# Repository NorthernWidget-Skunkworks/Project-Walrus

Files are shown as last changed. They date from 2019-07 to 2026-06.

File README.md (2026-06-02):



# The Walrus: A Pressure and Temperature Sensor for Water-Level and Barometric Measurements

Walrus pup; photo by Max Smith

***Our Walrus sensor, like this Walrus pup, is equally at home on land or in the water.*** *[Photo by Max Smith](https://commons.wikimedia.org/wiki/File:Walrus_-_Kamogawa_Seaworld_-_pup_-1.jpg)*

## Overview

The **Walrus** is an open-source sensor that measures temperature and pressure. It may be used in the air as a barometer or underwater as part of a system -- combined with barometric compensation -- to obtain changes in water level.

Walrus HardMount v0.2.0
***Hard-mount variant of the Walrus.*** Major components are labeled. The pads to attach the watertight plug for the cable (i.e. the "HardMount"), on left, are currently unpopulated. These may be used for this kind of connector, or may have wires soldered directly to them before being embedded in an epoxy or other potting (i.e., waterproofing and encapsulating) compound.

### Technical specifications

#### Size

Dimensions: 42.0 x 12.7 cm

>> ADD MASS once I get access to a lab balance again <<

#### Operating ranges

**Power**
* Input Voltage: 3.3 to 5.5 V DC
* Logic Voltage: 0 to Vcc (Will operate at same logic level as input power supply)

**Sensors**
* Temperature: -40 to +85 C
* Pressure, typical: 0 to 2 atm (i.e. barometer to 10 m water depth)
* Pressure, maximum, untested: 0 to 30 atm (i.e. barometer to 290 m water depth)
* Cable length: 3 m (I2C) or 1000 m (RS-485).

The pressure transducer contains an internal temperature sensor, and a secondary (and more accurate) external temperature sensor is also mounted on the *Walrus*. This external sensor is the [MCP9808](http://www.microchip.com/mymicrochip/filehandler.aspx?ddocname=en556196) in an 8-MSOP package. This sensor has a range of -40 to 125 C.

RS-485 communications allow for a signal to be transmitted over long distances, but require a device that can decode this signal, such as our [Project-Longbow](https://github.com/NorthernWidget-Skunkworks/Project-Longbow).

#### MS5803 pressure sensor variants

The pressure operating range and resolution depend on the MS5803 variant installed. All variants use the same footprint and firmware (with appropriate coefficient selection).

| Variant | Application | Range | Resolution @ OSR=4096 | Water depth equiv. |
|---|---|---|---|---|
| [MS5803-01BA](https://www.te.com/commerce/DocumentDelivery/DDEController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) | Barometer | 10–1300 mbar | ~0.012 mbar | ~0.12 mm |
| [MS5803-02BA](https://www.te.com/commerce/DocumentDelivery/DDEController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) | Shallow water | 0–2 bar | ~0.020 mbar | ~0.2 mm |
| [MS5803-05BA](https://www.te.com/commerce/DocumentDelivery/DDEController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) | Medium depth | 0–6 bar | ~0.050 mbar | ~0.5 mm |
| [MS5803-14BA](https://www.te.com/commerce/DocumentDelivery/DDEController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) | Deep water | 0–14 bar | ~0.200 mbar | ~2 mm |

The **MS5803-02BA** is the standard variant (pressure measurements to ~10 m water depth). The **MS5803-01BA** converts the Walrus into a high-resolution barometer. 1 mbar ≈ 1 cm of freshwater at standard conditions.

Pressure values are stored in the I2C register map as µBar (int32). All variants fit within int32 range (~2.1 billion µBar max).

#### Resolution

Pressure: see MS5803 variant table above
Temperature sensor within pressure transducer (typical): +/- 2.0 C
External temperature sensor (typical): +/- 0.5 C

## Circuit board and assembly

The Walrus comes in two forms:
* [Large form factor, through-hole mount](https://github.com/NorthernWidget-Skunkworks/Project-TPDH-Walrus/tree/master/Hardware_LargePTH): This is the legacy board with support for I2C and full-duplex RS-485 communication
* [Smaller form factor, solder pads for wires or a waterproof plug](https://github.com/NorthernWidget-Skunkworks/Project-TPDH-Walrus/tree/master/Hardware_HardMount): This current version makes better use of board space and utilizes a half-duplex RS-485 bus in addition to an I2C bus.

### Files

The files for production are located in folders starting with the word "Hardware". These folders contain:

* "\*.brd" and "\*.sch" files. These are the circuit board and its schematic for use with the EAGLE CAD software, which you can download for free: https://www.autodesk.com/products/eagle/free-download
* A "\*.csv" file that contains the "BoM" -- the bill of materials. This lists all required parts to construct the board
* A ZIP archive containing a set of "Gerber" files. These are the files that machines use to create a circuit board and a stencil to help you to apply solder paste (see below)

### Circuit board specifications

* 2-layer copper
* Minimum trace width: 0.2 mm
* Single-sided
* Surface mount components

All Walrus boards are **single-sided** and use only **surface-mount components** for rapid fabrication using standard equipment.

### Producing circuit boards

We strongly recommend that circuit boards be printed by a reputible manufacturer. Many such industries exist in China, India, and developing or developed countries.

### Populating circuit boards

Before you can start to populate the circuit board, meaning adding components to it, you will need solder paste and a stencil. If you have access to a laser cutter, you can create your own stencil (https://learn.adafruit.com/smt-manufacturing/laser-cut-stencils). If you do not, the company that prints the circuit boards should be able to provide one. If all else fails, you can try to cut out a stencil with a small knife, or use a solder-paste syringe, though both of these methods can lead to difficulties (such as bridged connections). Additional information on how to stencil can be found here: https://www.sparkfun.com/tutorials/58.

To help you in using the stencil, we provide STL files for 3D-printable plates in each of the hardware directories. These plates hold the board in place and provide a level surface on which to use the stencil.

>> ADD PLATE FOR HARDMOUNT <<

After this, you can use a tweezers and steady hands, or a pick-and-place machine, to gently place each component over the right pads, and in the right orientation. Do not worry if they are slightly misaligned; the surface tension of the solderi, once it is melted, will help to rotate the components into place.

### Reflowing circuit boards

"Reflowing" is the process of heating solder until it flows and attaches to components. A basic introduction is here: https://learn.sparkfun.com/tutorials/electronics-assembly/reflow

There are four major ways to reflow:
1. Using a professional oven (see link above)
2. With a customized toaster oven: See https://www.sparkfun.com/tutorials/60, and a basic internet search will show you many, many other ideas
3. You can also use a simple electrical skillet -- the kind that you might use to make some food. https://www.sparkfun.com/tutorials/59
4. Using a hot-air rework station; this is a bit time-intensive, but lets you control the heat, and I often use it for small boards. https://learn.sparkfun.com/tutorials/how-to-use-a-hot-air-rework-station/all

After reflowing, you may need to clean up jumped connections using **solder wick**.

### Debugging circuit boards

After reflow is complete, check if everything worked. Do you have any jumped connections? Any remaining solder paste that hasn't been reflowed? This can be the trickiest part, and one for which access to a multimeter is essential. An oscilloscope and a digital logical analyzer can help too. Debugging electronic circuit boards is a process that requires significant skill and practice, so be sure that you can work with someone with some expertise. I would suggest an electrical engineering student or professor at a local university.

## Wiring and pinout

"Pin" is the name of the pin as labeled on the board. "Wire" is the color of the [Alpha Wire 5004C cable](https://www.digikey.com/product-detail/en/alpha-wire/5004C-SL001/5004CSL001-ND/484976) that we use; you may use something different based on what manufacturers exist where you are; that's okay, just record the color convention! (We sometimes use another cable in which we use a white wire for SDA and a green wire for SCL, but have found that Alpha Wire brand works best.)

>> Add image of cable ends (optional) and find how to integrate with housing section; cabling is a distinct topic, but the step of attaching the cable lies within the housing-construction step <<

### HardMount with plug

Here we assume that you are using standard Alpha Wire cables with waterproof attachments, available in [3-meter](https://www.digikey.com/en/products/detail/alpha-wire/AR0400101-SL357/6555492) and [1-meter](https://www.digikey.com/en/products/detail/alpha-wire/AR0400101-SL356/6555491) lengths; the 3-meter length is our standard because this is the longest that it can be and still communicate reliably via I2C. Because of the wire insulation colors available for these cables and the locations of their attachment points to the [4-pin "HardMount" plug](https://www.digikey.com/product-detail/en/te-connectivity-amp-connectors/1838893-2/A97650-ND/1764165) ([3D model](https://www.traceparts.com/en/product/allied-electronics-automation-m12-panel-mnt-male-4-way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)), **our HardMount devices do NOT match standard wire-color definitions (or any kind of standard)**. Wire-color definitions are:

| **Color** | **Connection** |
|---|---|
| Brown | V+ (3.3-5.5 V) |
| White | GND |
| Black | SIG1: SDA or RS-485 A |
| Blue | SIG2: SCL or RS-485 B |

### Large-form-factor/PTH design: standard wiring suggestion

*These are our more standard wire-color suggestions*

| **Color** | **Connection** |
|---|---|
| Red | V+ (3.3-5.5 V) |
| Black | GND |
| Brown | SIG1: SDA or RS-485 A (RX+, TX+) |
| Orange | SIG2: SCL or RS-485 B (RX-, TX-) |

If you attach your own wire, pins on the Walrus are as follows, looking at the top side with the screw hole away from you:
* Top left: SIG1: SDA for I2C; A (+) for RS-485
* Top right: SIG 2: SCL for I2C; B (-) for RS-485
* Bottom left: VCC (3.3V to 5.5V)
* Bottom right: GND

HardMount attachment points

## Upload the firmware

### Downloading and installing the Arduino IDE

Go to https://www.arduino.cc/en/main/software. Choose the proper IDE version for your computer. For Windows, we suggest the non-app version to have more control over Arduino; this might change in the future. You will have to add custom libraries, so the web version will not work (at least, as of the time of writing). Download and install the Arduino IDE. Open it to begin the next steps.

### AVR ISP

To install firmware on the Walrus, you use the [2x3-pin ICSP (also called ISP) header](https://www.digikey.com/product-detail/en/3m/929665-09-03-I/3M156313-06-ND/681796) with a special device called an "in-circuit system programmer" (or just "in-system programmer; yup, that's what the acronym stands for).

Many devices exist to upload firmware, including:
* The official [AVR ISP mkII](http://ww1.microchip.com/downloads/en/DeviceDoc/Atmel-42093-AVR-ISP-mkII_UserGuide.pdf) (no longer produced but available used)
* Using an [Arduino as an ISP](https://www.arduino.cc/en/tutorial/arduinoISP)
* The versatile [Olimex AVR-ISP-MK2](https://www.olimex.com/Products/AVR/Programmers/AVR-ISP-MK2/open-source-hardware)
* The [Adafruit USBtinyISP](https://www.adafruit.com/product/46)

***Note: Be sure to download and/or update drivers for your ISP.***

### Uploading the firmware

Using an AVR ISP, upload the proper firmware programs from the ["Firmware" directory](Firmware) in this repository using the Arduino software:
* Large form factor PTH board
  * I2C mode: No firmware required, but fuses must be set (see instructions, below)
  * RS-485 mode: [Longbow_2BA_0x6B](Firmware/Longbow_2BA_0x6B) (This firmware is for the 02BA; you will need to switch these with other coefficients, available in the commented and uncommented lines of /Firmware/Walrus_I2C_5BA, to modify this for a different transducer pressure range.)
* Small form factor hard-mount board
  * I2C mode: Set the fuses (see instructions below) and then upload [Walrus_I2C_5BA](/Firmware/Walrus_I2C_5BA/) (This firmware is for the 05BA; there are lines in this code to comment and uncomment to modify it for other versions of the Walrus.)
  * RS-485 mode: [Longbow_2BA_0x6B_HalfDuplex](Firmware/Longbow_2BA_0x6B_HalfDuplex) (This firmware is for the 02BA; you will need to switch these with other coefficients, available in the commented and uncommented lines of /Firmware/Walrus_I2C_5BA, to modify this for a different transducer pressure range.)

>> @bschulz1701: could you provide a link to the repo (is it TPDH lib) for "  * I2C mode: No firmware required. Library communicates directly with sensors via their built-in I2C addresses."

**Instructions:**

1. Open the Arduino IDE.
2. Follow [these instructions](https://github.com/SpenceKonde/ATTinyCore/blob/master/Installation.md) to install the [ATTinyCore board definitions](https://github.com/SpenceKonde/ATTinyCore)
3. Select [ATTiny1634](https://github.com/SpenceKonde/ATTinyCore/blob/master/avr/extras/ATtiny_1634.md) **(No bootloader)**
4. Plug your ISP of choice into your computer (via a USB cable) and onto the 6-pin header. There are two ways to place it on; the header is aligned such that the ribbon cable should be facing away from the board while programming. If this fails without being able to upload, try flipping the header around. This should both power the board and provide communications.
5. Go to Tools --> Programmer and select the appropriate programmer based on what you are using.
6. Go to Tools --> Burn Bootloader. Yes, we know that you just selected "ATTiny1634 (No bootloader)", but this step sets the fuses, which configure their internal oscillator and brown-out detection.
7. Unless you are configuring a large-form-factor Walrus in I2C mode (in which case you are now done), open the appropriate firmware (linked above). Then go to Sketch --> Upload Using Programmer. After several seconds, you learn whether you succeeded or failed. Hopefully it worked!

Upload using programmer

***Uploading using the in-system programmer.***

***Important note for Linux users:*** You must supply permissions to the Arduino IDE for it to be able to use the ICSP, or you will have to run it using `sudo`. The former option is better; the latter is easier in the moment.

## Register map and firmware internals

The Walrus firmware runs on an ATtiny1634 microcontroller and exposes an I2C register map to the host logger. The default I2C address is `0x4D`.

Two layouts exist: the **current firmware** (deployed) and the **proposed** layout under [NW-Device-Specification](https://github.com/NorthernWidget/NW-Device-Specification) Schema 1, which the firmware will be updated to implement.

### Current register map (deployed firmware)

26-byte array. Identity fields (MODEL, GROUPID, INDID, FIRMWAREID) mixed into sensor data. Status ready flag is bit 7.

```
0x00        CTRL/Status   bit 7=ready; bits 1:0=update rate selector (0–3)
0x01        —             unused
0x02–0x05   Pressure      int32, µBar (library: val/1000.0 → mBar)
0x06–0x09   Temp ext      int32, 1/10000 °C (MCP9808 external sensor)
0x0A–0x0D   Temp MS5803   int32, 1/10000 °C (MS5803 internal sensor)
0x0E–0x0F   MODEL         uint16 (0x5702)
0x10–0x11   —             gap (nothing loaded)
0x12–0x13   GROUPID       uint16
0x14–0x15   INDID         uint16
0x16–0x17   FIRMWAREID    uint16 (0x0001)
```

### Proposed register map (NW-Device-Specification Schema 1)

Two 32-byte pages. Identity moves entirely to Page 0 (EEPROM). Sensor data in Page 1 (SRAM). No calibration page (MS5803 coefficients are read from its internal PROM at startup).

**Page 0 (0x00–0x1F) — Identity (EEPROM)**

```
Block 0 (0x00–0x07)   Core identity
  0x00        0x01              Schema (NW-Device-Specification v1)
  0x01–0x06   'W','a','l','r','u','s'   Device name (ASCII)
  0x07        0x00              Null padding

Block 1 (0x08–0x0F)   Version
  0x08        HW major
  0x09        HW minor
  0x0A        FW patch          (NW combined-repo convention)
  0x0B–0x0D   0x00,0x00,0x00    Unused (combined repo)
  0x0E–0x0F   0x00,0x00         Reserved

Block 2 (0x10–0x17)   Serial number
  0x10–0x11   0x5702            Board type ('W'=0x57, revision index 2; matches MODEL)
  0x12–0x13   [manufacture]     Group ID
  0x14–0x15   [manufacture]     Unique ID
  0x16–0x17   0x00,0x00         FirmwareID (legacy, reserved)

Block 3 (0x18–0x1F)   Integrity + administration
  0x18–0x1C   0x00 ×5           Reserved
  0x1D        0x00              Magic byte (reserved; purpose TBD)
  0x1E        [computed]        CRC-8 of bytes 0x00–0x1D
  0x1F        0x4D              I2C address (writable; 0xFF = use default)
```

**Page 1 (0x20–0x3F) — Sensor data (SRAM)**

```
Block 0 (0x20–0x27)   MS5803 — pressure + temperature
  0x20        Status       bit 0=ready, bit 1=MS5803 fault, bit 2=ext temp fault,
                           bit 7=pan-fault
  0x21        Extended faults (reserved, 0x00)
  0x22–0x25   Pressure     int32, µBar, little-endian
  0x26–0x27   Temp MS5803  int16, 0.01 °C, little-endian

Block 1 (0x28–0x2F)   External temperature sensor (MCP9808)
  0x28–0x29   Temp ext     int16, 0.01 °C, little-endian
  0x2A–0x2F   Reserved

Block 2–3 (0x30–0x3F)   Reserved
```

## Housing

### Large-form-factor PTH design

Walrus PTH v0.0.0 with enclosure

***Walrus v0.0.0 PTH and its housing.*** *Left: 3D-printed top of the housing; the slits are to prevent large material from hitting the sensor. Center: the bottom of the housing. Self-tapping holes are to screw the board onto this housing. The cable entering the housing through a tightly-fitting hole on the "south" side of the image has not yet been stripped to expose the ends of the individual wires. A different variant of the housing is longer to allow the user to strip more of the cable if desired while maintaining the cable jacketing in contact with the hole. Top right: Walrus v0.0.0. This fully-functional initial version is significantly larger than the current unit. Note the pressure transducer (white circle) at top left, and the fact that this has pins and hardware for a full-duplex RS-485 connection. Bottom right: U.S. penny for scale; 19.05 mm (0.75 inch) diameter.*

### HardMount design

Render of Walrus enclosure
***Render of the enclosure design.*** *The epoxy encapsulation tray sits within a wider cylinder containing a screen designed to keep sediment out. Design still in progress (19 June 2020).*

### How to build

#### Materials and components required

##### All models

* 3D printer filament: ABS suggested
* Two-part epoxy: [3M DP270 Clear](https://multimedia.3m.com/mws/media/66773O/3mtm-scotch-weldtm-epoxy-potting-compound-adhesive-dp270.pdf); can be purchased from [McMaster-Carr](https://www.mcmaster.com/7467A274)
* Conformal coating to help protect components during epoxy encapsulation. We suggest [MG 419D](https://www.mgchemicals.com/products/conformal-coatings/acrylic-conformal-coating-419d) ([Digi-Key purchase link](https://www.digikey.com/product-detail/en/mg-chemicals/419D-55ML/473-1388-ND)). If you prefer a silicone conformal coat, we suggest [MG 422C](https://www.mgchemicals.com/products/conformal-coatings/422c-silicone-conformal-coating), though we recommend this instead for an external (rather than internal, as this will be), flexible coat.

##### HardMount with Plug

* [4-pin "HardMount" plug](https://www.digikey.com/product-detail/en/te-connectivity-amp-connectors/1838893-2/A97650-ND/1764165) ([3D model](https://www.traceparts.com/en/product/allied-electronics-automation-m12-panel-mnt-male-4-way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))
* HardMount cable: **Alpha Wire AR0400105-SL357** (-40 PVC jacket)
  * [Alpha Wire page](http://www.Alpha Wire.com/en/Products/Connectivity/AlphaConnect/Cordsets/AR0400105)
  * [Example from DigiKey](https://www.digikey.com/product-detail/en/alpha-wire/AR0400105-SL357/AR0400105SL357-ND/6555497)
  * Comes in a [variety of lengths from 0.6 to 20 meters](http://www.Alpha Wire.com/en/Products/Connectivity/AlphaConnect/Cordsets/AR0400105) ([Digi-Key search results](https://www.digikey.com/products/en/cable-assemblies/circular-cable-assemblies/448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))
  * User may choose a cable that terminates in a plug, alongside a matching recepticle in the wall of the data-logger box, for a specialized solution that does not require cable glands.
* One [#2-56 x 3/16" thread-cutting screw](https://www.fastenal.com/products/details/0143391) per board to fasten it to the housing for the epoxy encapsulation

##### PTH or "HardMount" design without plug

* 7x [\#4-24 self-tapping screws](https://www.polycase.com/screws-mbr-100) ([Additional link: untested but probably identical screw from Fastenal](https://www.fastenal.com/products/details/32244))
  * 3x to hold board in place
  * 4x to to attach the lid of the 3D-printed enclosure

*Assuming that we are using a 4-wire connection instead of the full-bridge RS-485 (supported by the large-form-factor/PTH board) because this is being phased out in favor of a 4-wire half-bridge.*

* [4-conductor Alpha Wire](https://www.digikey.com/product-detail/en/alpha-wire/5004C-SL001/5004CSL001-ND/484976), soldered to pads or rings

#### 3D printing the housing

Subfolders of the "3Dprint" directory contain "STL" files that you can use with a program called "[Slic3r](https://slic3r.org/)" to create 3-D printable parts for your housing. Assuming that you have a Prusa 3D printer, you will want to download the [Prusa variant of Slic3r](https://www.prusa3d.com/prusaslicer/). This comes with the appropriate setup files and information to help you configure the printer and print your parts.

>> Link to all housings once designed <<

>> TO DO: Options for HardMount with (and perhaps without) the plug. <<

#### Cabling

##### HardMount with Plug

Solder the HardMount plug onto the four SMD pads with the notch (for plug orientation) at the bottom side of the board. The best way to do this is to:
* Add small pillows of solder to each of the four pads, enough to create contact with the HardMount solder cups but not so much that it is not possible to slide the HardMount plug over them.
* Slide the HardMount plug on; it will take a bit of finesse to keep it from being pushed off of the solder pillows.
* Using some Blu Tack (or equivalent), fix the board and HardMount plug in place
* Double-check that the notch in the HardMount plug is on the back side of the board
* Solder on the first connection
* Check whether the board is straight; reflow the solder as needed until the connection is secure
* Solder the second connection
* Flip the board, ensuring that it is straight (if not, make changes)
* Solder the other two solder-cup connections

##### PTH or "HardMount" design without plug

Optionally, pass the cable through its hole in the 3D-printed enclosure bottom for the pour-over epoxy encapsulation. This means that you will not later need to pass the full length of the cable through the hole!

Next, solder the cable through the rings or onto the SMD pads. Ensure that all connections are solid prior to encapsulation. The encapsulation process will strain-relieve the cable.

#### Potting

>> @bschulz1701: with this epoxy, do we need to conformally coat the boards first?

After creating the housing, affix the logger to it using the \#4-24 screws listed above. If the design includes an integrated cable (instead of a HardMount plug), MAKE SURE that a cable of the desired length is attached beforehand! Otherwise, MAKE SURE that a HardMount plug is attached beforehand!

>> @superchap123: Your clip design would come in here too.

Before applying the epoxy, make sure that all zones where epoxy could leak out of the 3D-printed lower portion of the enclosure are sealed. The epoxy is somewhat viscous, so gaps need not be made completely airtight.

Next, pot the boards in 2-part epoxy (per the supplies list above, we suggest [3M DP270 Clear](https://multimedia.3m.com/mws/media/66773O/3mtm-scotch-weldtm-epoxy-potting-compound-adhesive-dp270.pdf); can be purchased from [McMaster-Carr](https://www.mcmaster.com/7467A274)). Be careful to fully cover everything except for the white inside membrane on the pressure transducer. If epoxy touches this, it is rendered unreliable or useless.

>> Walk through assembly with images <<

Potting the large form factor Walrus
***Potting the large-form-factor Walrus.*** *3D print designs for this lower/tray portion and the to-be-attached lid are included [within this repository in the "3Dprint" folder](https://github.com/NorthernWidget-Skunkworks/Project-Walrus/tree/master/3Dprint/HousingLargePTH).*

## Wiring to logger

These instructions assume that you are using a [Margay](https://github.com/NorthernWidget-Skunkworks/Project-Margay) or [Okapi](https://github.com/NorthernWidget-Skunkworks/Project-Okapi) data logger. If this is not the case, similar pins are available on a generic Arduino board.

### HardMount Plug

Pass the cable through the housing to the logger, ideally using a cable gland that you can tighten on the box containing the logger: this can provide waterproofing as well as some strain relief. Follow the table in the [Wiring and pinout](#Wiring-and-pinout) section to attach individual wires to the appropriate pins on the data logger and (if needed) RS-485 converter. In bulleted-list form, with colors given for [Alpha Wire 5004C](https://www.digikey.com/product-detail/en/alpha-wire/5004C-SL001/5004CSL001-ND/484976):

### Power

* V- (Walrus) to GND or V- (Logger)
* V+ (Walrus) to a positive voltage source between 3.3 and 5.5 V (Logger)

#### I2C

If using the sensor in I2C mode, attach the signal wires as follows:
* SIG1 (Walrus) to SDA (Logger)
* SIG2 (Walrus) to SCL (Logger)

#### RS-485

If using the sensor in RS-485 mode, attach the signal wires to the Longbow Backpack as follows:
* SIG1 (Walrus) to A+ (Longbow)
* SIG2 (Walrus) to B- (Longbow)
(You may use another RS-485 converter, in which case the wiring is up to you!)

**Then use another set of four wires to connect the Longbow to the logger:**
* GND to GND
* Vin to a 3.3 to 5.5 V power source
* SDA to SDA
* SCL to SCL
We recommend [Pololu's pre-crimped wires](https://www.pololu.com/category/71/wires-with-pre-crimped-terminals) for this with a male terminal, as it ensures that you can have these four wires in the proper order for both the Walrus and the data logger. For this reason, Northern Widget data loggers ([Margay](https://github.com/NorthernWidget-Skunkworks/Project-Margay) and [Okapi](https://github.com/NorthernWidget-Skunkworks/Project-Okapi)) always have these four pins in the order:
* GND
* V+
* SDA
* SCL

## Writing a program to connect to the Walrus sensor

After uploading the Walrus firmware, you should be able to use any standard Arduino device to connect to it and read its data.

The firmware uploaded to the Arduino device should include the [Walrus library](https://github.com/NorthernWidget-Skunkworks/Walrus_Library) as demonstrated below. Documentation for the Walrus library, auto-generated using doxygen, is available on its linked GitHub page.

### Very simple Arduino code

#### I2C

This code is intended for any generic Arduino system.

>> Note: Not all of this code is built yet. THIS IS A TEMPLATE!

```c++
// Include the Walrus library
#include "Walrus_I2C.h"

// Declare variables -- just as strings
String header;
String data;

// Instantiate class
Walrus myWalrus;

void setup(){
    // Begin Serial connection to computer at 38400 baud
    Serial.begin(38400);
    // Obtain the header just once
    header = myWalrus.getHeader();
    // Print the header to the serial monitor
    Serial.println(header);
}

void loop(){
    // Take one reading every (10 + time to take reading) seconds
    data = myWalrus.getString();
    // and print it to the screen
    Serial.println(data);
    delay(10000); // Wait 10 seconds before the next reading, inefficiently
}
```

#### RS-485

***Not yet developed.***

### Northern Widget Margay code

The [Margay data logger](github.com/NorthernWidget-Skunkworks/Project-Margay) is the lightweight and low-power open-source data-logging option from Northern Widget. It saves data to a local SD card and includes on-board status measurements and a low-drift real-time clock. We have written [a library to interface with the Margay](github.com/NorthernWidget-Skunkworks/Margay_Library), which can in turn be used to link the Margay with sensors.

#### I2C

```c++
// Include the Walrus library
#include "Margay.h"
#include "Walrus_I2C.h"

// Declare variables -- just as strings
String header;
String data;

// Instantiate classes
Walrus myWalrus;
Margay Logger; // Margay v2.2; UPDATE CODE TO INDICATE THIS

// Empty header to start; will include sensor labels and information
String Header = "";

// I2CVals for Walrus
uint8_t I2CVals[] = {0x4D}; // DEFAULT

//Number of seconds between readings
uint32_t updateRate = 60;

void setup(){
    Header = Header + myWalrus.getHeader();
    Logger.begin(I2CVals, sizeof(I2CVals), Header);
    initialize();
}

void loop(){
    initialize();
    Logger.run(update, updateRate);
}

String update() {
    initialize();
    return myWalrus.getString();
}

void initialize(){
    myWalrus.begin();
}
```

#### RS-485

***Not yet developed.***

## Deployment

Pre-deployment check:
* Ensure that the cable is appropriately strain relieved on the logger end (the screw plug or epoxy, depending on model, handles this on the sensor end).
* Check cable for nicks or tears; replace if needed.
* Ensure that the unit functions properly and gives good readings in the lab
* Check that you have programmed the desired reading duration
* Ensure that the transducer for your Walrus functions over the desired pressure range

Once you are ready, you can deploy your sensor in the river, lake, or atmosphere that you hope to measure. Remember that you must correct all pressure measuremennts for barometric pressure in order to recover a water level. If the water is saline or heavily sediment laden, you must know the salinity or sediment-adjusted density as well.

## NW-Device-Specification — Schema 1, Page 0

Implements [NW-Device-Specification](https://github.com/NorthernWidget/NW-Device-Specification) Schema 1. The 32-byte identity block (Page 0) is stored at the top of EEPROM:

```
Block 0:  Schema=0x01, Name='W','a','l','r','u','s',0x00
Block 1:  HW major=[mfr], HW minor=[mfr], FW patch=[mfr], 0x00,0x00,0x00, Reserved
Block 2:  Board type=0x5702 ('W'=0x57, rev 2), Group ID=[mfr], Unique ID=[mfr], FirmwareID=0x0000
Block 3:  Reserved, Magic=0x00, CRC=[computed], I2C address=0x57
```

Legacy deployed units use I²C address `0x4D` (pre-Schema-1).

## Acknowledgments

Support for this project provided by:

UMN ESCI

WMO

<br/>
<br/>
<br />This work is licensed under a <a rel="license" href="http://creativecommons.org/licenses/by-sa/4.0/">Creative Commons Attribution-ShareAlike 4.0 International License</a>.

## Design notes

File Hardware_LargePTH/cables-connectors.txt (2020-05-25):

Cable for non-HardMount version: Alpha Wire 5004C: https://www.digikey.com/product-detail/en/alpha-wire/5004C-SL001/5004CSL001-ND/484976

Two options for ICSP connector:
Standard-height 2x3 M header: https://www.digikey.com/product-detail/en/3m/929665-09-03-I/3M156313-06-ND/681796
Tall 2-3 M header for extra clearance above the epoxy fill: https://www.digikey.com/product-detail/en/3m/929715-11-03-EU/3M156380-06-ND/3834482

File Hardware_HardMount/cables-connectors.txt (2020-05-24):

"HardMount" plug: TE Connectivity 1838893-2: https://www.digikey.com/product-detail/en/te-connectivity-amp-connectors/1838893-2/A97650-ND/1764165
"HardMount cable: Alpha Wire AR0400105 SL357: https://www.digikey.com/product-detail/en/alpha-wire/AR0400105-SL357/AR0400105SL357-ND/6555497
Cable for non-HardMount version: Alpha Wire 5004C: https://www.digikey.com/product-detail/en/alpha-wire/5004C-SL001/5004CSL001-ND/484976

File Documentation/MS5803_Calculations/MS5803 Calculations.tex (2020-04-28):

\documentclass[10pt,a4paper]{report}
\usepackage[utf8]{inputenc}
\usepackage{amsmath}
\usepackage{amsfonts}
\usepackage{amssymb}

\usepackage[svgnames]{xcolor} % Required for colour specification
\usepackage{amsmath}
\newcommand*{\plogo}{\fbox{$\mathcal{PL}$}} % Generic dummy publisher logo
\usepackage{graphicx}
\usepackage[export]{adjustbox}
\usepackage{wrapfig}
\usepackage{float}

\usepackage[margin=0.75in]{geometry}

\include{nwseal_slogan_linear_100px.PNG}

\begin{document}

\begin{titlepage} % Suppresses headers and footers on the title page
%	\begin{figure}[H]
%
%\begin{wrapfigure}{l}{0.5\textwidth}

%%\caption{Caption1}
%\label{fig:subim1}
%\end{wrapfigure}
%
%\end{figure}

\Huge
\begin{flushright}
\textbf{Application Note}
\end{flushright}
	\raggedleft % Right align everything
	
	\vspace*{\baselineskip} % Whitespace at the top of the page
	
	%------------------------------------------------
	%	Author
	%------------------------------------------------
	
	{\Large Written by\\Bobby Schulz} % Author name
	
	\vspace*{0.167\textheight} % Whitespace before the title
	
	%------------------------------------------------
	%	Title and subtitle
	%------------------------------------------------
	
	\textbf{\LARGE Sensors}\\[\baselineskip] % First title line
	
	%{\textcolor{Red}{\Huge \LaTeX ~Templates}}\\[\baselineskip] % Main title line which draws the focus of the reader
	MS5803 Pressure and Temperature Sensor 
	{\Large \textit{Conversion Calculations}} % Subtitle
	
	\vfill % Whitespace between the titles and the publisher
	
	%------------------------------------------------
	%	Publisher
	%------------------------------------------------
	
	{\large Developed and Distributed by Northern Widget LLC} % Publisher and logo
	
	\vspace*{3\baselineskip} % Whitespace at the bottom of the page

\end{titlepage}

%\begin{figure}[H]
%
%\begin{wrapfigure}{l}{0.5\textwidth}
%\includegraphics[width=0.5\textwidth, left]{nwseal_slogan_linear_100px.PNG}
%%\caption{Caption1}
%\label{fig:subim1}
%\end{wrapfigure}
%
%\end{figure}

%\large
%\begin{flushright}
%Application Note
%\end{flushright}

%\pagebreak

\begin{center}
\Large
MS5803 Conversion Calculations and Coefficients
\end{center}

\normalsize

Equations used for the conversion process between the digital measurements and the resulting readings can be grouped into two categories, first order and second order, we will deal with the first order conversion first
\\
\\
Values retrieved from the MS5803 unit are $C1, C2, C3, C4, C5, C6, D1,D2$
To calculate temperature, Eqn. \ref{eqn:TempDif} and Eqn. \ref{eqn:Temp}. These equations are constant across all MS5803 models

\begin{equation}
dT = D2 - T_{REF} = D2 - C5 \times 2^8
\label{eqn:TempDif}
\end{equation}

\begin{equation}
TEMP = 2000 + dT \times C6 / 2^{23}
\label{eqn:Temp}
\end{equation}

Next, to calculate pressure, we will use Eqn. \ref{eqn:Offset}, Eqn. \ref{eqn:Sens}, Eqn. \ref{eqn:Pressure} and Eqn. \ref{eqn:PressureBar}. In this case $OFF$ is the offset to the reference temperature, $SENS$ is the sensitivity at the actual temperature, and finally, $P$ is the pressure. We introduce the coefficients $\mathbin{\color{red}A, B, C, D, E}$ which vary depending on which sensor model is being used, as well as $P_{BAR}$ which is the pressure given in Bars.

\begin{equation}
OFF = C2 \times 2^{\mathbin{\color{red}A}} + (C4 \times dT)/2^{\mathbin{\color{red}B}}
\label{eqn:Offset}
\end{equation}

\begin{equation}
SENS = C1 \times 2^{\mathbin{\color{red}C}} + (C3\times dT) / 2^{\mathbin{\color{red}D}}
\label{eqn:Sens}
\end{equation}

\begin{equation}
P = D1 \times SENSE - OFF = (D1 \times SENS/2^{21} - OFF)/2^{15}
\label{eqn:Pressure}
\end{equation}

\begin{equation}
P_{BAR} = P/{\mathbin{\color{red}E}}
\label{eqn:PressureBar}
\end{equation}

This provides us with a first order conversion, to improve accuracy we must use a second order compensation for temperature and pressure. This is done using Eqn. \ref{eqn:T2}, Eqn. \ref{eqn:OFF2}, and Eqn. \ref{eqn:SENS2}.
We introduce the coefficients $\mathbin{\color{red}F, G, H, I, J, K, L, M, O, P}$
\begin{equation}
T2 = 
\begin{cases}
{\mathbin{\color{red}N}} \times dT^2 / 2^{\mathbin{\color{red}O}}  & TEMP > 20Deg \\
{\mathbin{\color{red}F}} \times dT^2 / 2^{\mathbin{\color{red}G}} &  TEMP < 20 Deg 
\label{eqn:T2}
\end{cases}
\end{equation}

\begin{equation}
OFF2 = 
\begin{cases}
 {\mathbin{\color{red}P}} (TEMP - 2000)^2 / 2^ 4 & TEMP > 20Deg \\
 {\mathbin{\color{red}H}} (TEMP - 2000)^2 / 2^ {\mathbin{\color{red}I}} & TEMP < 20Deg \\
 {\mathbin{\color{red}H}} (TEMP - 2000)^2 / 2^ {\mathbin{\color{red}I}} + {\mathbin{\color{red}L}} (TEMP + 1500)^2 & TEMP < -15Deg 
\label{eqn:OFF2}
\end{cases}
\end{equation}

\begin{equation}
SENS2 = 
\begin{cases}
 {\mathbin{\color{red}H}} (TEMP - 2000)^2 / 2^ {\mathbin{\color{red}I}} - {\mathbin{\color{red}M}} (TEMP - 4500)^2 & TEMP > 45 Deg \ \text{\footnote{Only for BA01 Model!}} \\
 0 & TEMP > 20Deg \\
 {\mathbin{\color{red}J}} (TEMP - 2000)^2 / 2^ {\mathbin{\color{red}K}} & TEMP < 20Deg \\
 {\mathbin{\color{red}H}} (TEMP - 2000)^2 / 2^ {\mathbin{\color{red}I}} + {\mathbin{\color{red}M}} (TEMP + 1500)^2 & TEMP < -15Deg
\label{eqn:SENS2}
\end{cases}
\end{equation}

\footnotetext{NOTE: Only for BA01 Model! For all others, discount this range and let $SENS2 = 0$ for $TEMP > 20 Deg$}

\newpage
The coefficients used in these equations are shown in detail for all avaliable MS5803 sensor models in Table. \ref{tab:Coef}

\begin{table}[!h]
\centering

\begin{tabular}{|l|l|l|l|l|l|l|}
\hline
Coef \textbackslash Sensor & BA01 & BA02 & BA05 & BA07 & BA14 & BA30 \\ \hline
A           & 16   & 17   & 18   & 18   & 16   & 16   \\ \hline
B           & 7    & 6    & 5    & 5    & 7    & 7    \\ \hline
C           & 15   & 16   & 17   & 17   & 15   & 15   \\ \hline
D           & 8    & 7    & 7    & 6    & 8    & 8    \\ \hline
E           & 100  & 100  & 90.9 & 25   & 10   & 10   \\ \hline
F           & 1    & 1    & 3    & 3    & 3    & 3    \\ \hline
G           & 31   & 31   & 33   & 33   & 33   & 33   \\ \hline
H           & 3    & 61   & 3    & 3    & 3    & 3    \\ \hline
I           & 0    & 4    & 3    & 3    & 1    & 1    \\ \hline
J           & 7    & 2    & 7    & 7    & 5    & 5    \\ \hline
K           & 0    & 0    & 3    & 3    & 3    & 7    \\ \hline
L           & 0    & 20   & 0    & 0    & 7    & 7    \\ \hline
M           & 2    & 12   & 3    & 3    & 4    & 4    \\ \hline
N           & 0    & 0    & 0    & 0    & 7    & 7    \\ \hline
O           & 0    & 0    & 0    & 0    & 37   & 37   \\ \hline
P           & 0    & 0    & 0    & 0    & 1    & 1    \\ \hline
\end{tabular}

\caption{This table contains the coefficients to be used for all models of the MS5803}
\label{tab:Coef}
\end{table}

\vspace*{\fill}
\begin{center}
\textit{This work was assembled by those at Northern Widget LLC}
\end{center}

\end{document}

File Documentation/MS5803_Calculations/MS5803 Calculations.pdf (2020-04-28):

# Application Note

## Written by

## Bobby Schulz

# Sensors

# MS5803 Pressure and Temperature Sensor

## Conversion Calculations

Developed and Distributed by Northern Widget LLC

## MS5803 Conversion Calculations and Coefficients

Equations used for the conversion process between the digital measurements and the resulting readings can be grouped into two categories, first order and second order, we will deal with the first order conversion first

Values retrieved from the MS5803 unit are C1, C2, C3, C4, C5, C6, D1, D2 To calculate temperature, Eqn. 1 and Eqn. 2. These equations are constant across all MS5803 models

dT = D2 − TREF = D2 − C5 × 2

8
(1)

T EMP = 2000 + dT × C6/2

23 | (2)

Next, to calculate pressure, we will use Eqn. 3, Eqn. 4, Eqn. 5 and Eqn. 6. In this case OF F is the offset to the reference temperature, SENS is the sensitivity at the actual temperature, and finally, P is the pressure. We introduce the coefficients A, B, C, D, E which vary depending on which sensor model is being used, as well as PBAR which is the pressure given in Bars.

OF F = C2 × 2

A + (C4 × dT)/2
B | (3)

SENS = C1 × 2

C + (C3 × dT)/2
D | (4)

P = D1 × SENSE − OF F = (D1 × SENS/2

21 − OF F)/2

15 | (5)
PBAR = P/E | (6)

This provides us with a first order conversion, to improve accuracy we must use a second order compensation for temperature and pressure. This is done using Eqn. 7, Eqn. 8, and Eqn. 9. We introduce the coefficients F, G, H, I, J, K, L, M, O, P
T2 = (
N × dT²/2

O T EMP > 20Deg
F × dT²/2

G T EMP < 20Deg

(7)

OF F2 =

P(T EMP − 2000)²/2

4 | T EMP > 20Deg
H(T EMP − 2000)²/2
I | T EMP < 20Deg
H(T EMP − 2000)²/2

I + L(T EMP + 1500)² T EMP < −15Deg

(8)

SENS2 =

H(T EMP − 2000)²/2

I − M(T EMP − 4500)² T EMP > 45Deg 1

0 | T EMP > 20Deg
J(T EMP − 2000)²/2
K | T EMP < 20Deg
H(T EMP − 2000)²/2

I + M(T EMP + 1500)² T EMP < −15Deg

(9)

1NOTE: Only for BA01 Model! For all others, discount this range and let SENS2 = 0 for T EMP > 20Deg

1

The coefficients used in these equations are shown in detail for all avaliable MS5803 sensor models in Table. 1

Coef \Sensor | BA01 | BA02 | BA05 | BA07 | BA14 | BA30
A | 16 | 17 | 18 | 18 | 16 | 16
B | 7 | 6 | 5 | 5 | 7 | 7
C | 15 | 16 | 17 | 17 | 15 | 15
D | 8 | 7 | 7 | 6 | 8 | 8
E | 100 | 100 | 90.9 | 25 | 10 | 10
F | 1 | 1 | 3 | 3 | 3 | 3
G | 31 | 31 | 33 | 33 | 33 | 33
H | 3 | 61 | 3 | 3 | 3 | 3
I | 0 | 4 | 3 | 3 | 1 | 1
J | 7 | 2 | 7 | 7 | 5 | 5
K | 0 | 0 | 3 | 3 | 3 | 7
L | 0 | 20 | 0 | 0 | 7 | 7
M | 2 | 12 | 3 | 3 | 4 | 4
N | 0 | 0 | 0 | 0 | 7 | 7
O | 0 | 0 | 0 | 0 | 37 | 37
P | 0 | 0 | 0 | 0 | 1 | 1

Table 1: This table contains the coefficients to be used for all models of the MS5803

This work was assembled by those at Northern Widget LLC

2

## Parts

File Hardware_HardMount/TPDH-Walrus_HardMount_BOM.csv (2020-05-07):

Qty | Value | Device | Package | Parts | Description | DIGIKEY | DISP | MF | MPN | PROD_ID | VALUE | VALUE_PART
1 |  | ATTINY1634QFN | QFN20 | U3 | ATtiny1634 8 bit AVR Microcontroller | ATTINY1634-MURCT-ND |  | Atmel | ATTINY1634-MUR
1 |  | MOUNTING_HOLE2_NP | 2_56 | H1 | Genaric Mechanical Mounting Hole | DNP |  | N/A | DNP
1 |  | TVSSM712 | SOT23-3 | D2 | Generic dual channel TVS diode | CDSOT23-SM712CT-ND |  | Bourns | CDSOT23-SM712
6 | 0.1uF | C-EU0.1UFC0402 | C0402 | C1, C2, C3, C6, C9, C10 | CAPACITOR, European symbol | 490-4759-1-ND |  | Murata | GCM155R71C104KA55D
1 | 100 | R-EU_100R0402 | R0402 | R6 | RESISTOR, European symbol | 311-100LRCT-ND |  | Yageo | RC0402FR-07100RL |  |  | 100
5 | 10k | R-EU_10KR0402 | R0402 | R2, R3, R4, R5, R8 | RESISTOR, European symbol | 311-10.0KLRCT-ND |  | Yageo | RC0402FR-0710KL |  |  | 10k
1 | 1k | R-EU_1KR0603 | R0603 | R1 | RESISTOR, European symbol | 311-1KLDCT-ND |  | Yageo | AC0603FR-071KL |  |  | 1k
2 | 1uF | C-EU1UFC0603 | C0603 | C4, C5 | CAPACITOR, European symbol | 1276-6524-1-ND |  | Samsung | 1276-6524-1-ND
1 | AVRISP-6 | AVRISP-6 | AVRISP | ISP1 | AVR ISP HEADER
1 | DMG3404 | MOSFET-NCH-DMG3404L | SOT23-3 | Q2 | N-channel MOSFETs | DMG3404L-7DICT-ND |  | Diodes Incorporated | DMG3404L-7 |  | DMG3404
1 | LEDBLUE0603 | LEDBLUE0603 | LED_0603 | D1 | Genaric LED | 732-4966-1-ND |  | Wurth | 150060BS75000
1 | LP39883.3VDBV | LP39883.3VDBV | DBV0005A | U5 | TPS7A05* - Ultra Low Power Ultra Low Dropout Linear Regulator with Power Good | LP3988IMF-3.3/NOPBCT-ND |  | TI | LP3988IMF-3.3/NOPB
1 | MCP9808MSOP | MCP9808MSOP | MSOP_8 | U4 | MCP9808 - Digital Temperature Sensor | MCP9808T-E/MSCT-ND |  | Microchip | MCP9808T-E/MS
1 | MS580302BA | MS580302BA | MS5803 | U1 | MS5803 - Minature Media Compatible Pressure Sensor | 223-1624-5-ND |  | TE Connectivity | MS580302BA01-00
1 | NS5A4684S | NS5A4684S | WQFN10 | U8 | NS5A4684S - Dual Analog Multiplexer (1:2) | NS5A4684SMNTAGOSCT-ND | NS5A4684 | ON Semiconductor | NS5A4684SMNTAG
1 | OSHW-LOGOM | OSHW-LOGOM | OSHW-LOGO-M | LOGO1 | Open-Source Hardware (OSHW) Logo | DNP |  | N/A | DNP
1 | POGO_PAD | POGO_PAD | POGO_PAD | U$12 | POGO Pad | DNP |  | N/A | DNP
1 | SN65HVD72DSOIC | SN65HVD72DSOIC | SO08 | U2 | SN65HVD72 - Half Duplex RS-485 Tranciver, with output enable | 296-39179-1-ND | SN65HVD72 | TI | SN65HVD72DR
1 | SOLDERCUP_CONN_QUAD | SOLDERCUP_CONN_QUAD | SOLDERCUP_CONN_QUAD | U$1 | Mounting pads for a M12 barel connector | A97650-ND |  | TE Connectivity | 1838893-2
1 | TXS0102DQM | TXS0102DQM | DQM_R-PX2SON-N8 | U7 | TXS0102 - 2 Channel Bidirectional Voltage Level Translator | 296-28435-1-ND |  | TI | TXS0102DQMR

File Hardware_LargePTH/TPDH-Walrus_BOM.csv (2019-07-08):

Qty | Value | Device | Package | Parts | Description | DIGIKEY | DISP | MF | MPN | PROD_ID | VALUE | VALUE_PART
10 |  | 2,15/1,0 | 2,15/1,0 | PAD1, PAD2, PAD3, PAD4, PAD5, PAD6, PAD7, PAD8, PAD9, PAD10 | THROUGH-HOLE PAD
1 |  | ATTINY1634QFN | QFN20 | U3 | ATtiny1634 8 bit AVR Microcontroller | ATTINY1634-MURCT-ND |  | Atmel | ATTINY1634-MUR
3 |  | MOUNTING_HOLE2_NP | 2_56 | H1, H2, H3 | Genaric Mechanical Mounting Hole
2 |  | R-EU_100R0402 | R0402 | R6, R7 | RESISTOR, European symbol | 311-100LRCT-ND |  | Yageo | RC0402FR-07100RL |  |  | 100
9 | 0.1uF | C-EU0.1UFC0402 | C0402 | C1, C2, C3, C4, C6, C7, C8, C9, C10 | CAPACITOR, European symbol | 490-4759-1-ND |  | Murata | GCM155R71C104KA55D
4 | 10k | R-EU_10KR0402 | R0402 | R3, R4, R5, R8 | RESISTOR, European symbol | 311-10.0KHRCT-ND |  | Yageo | RC0603FR-0710KL |  |  | 10k
1 | 10k | R-EU_P10KR0603 | R0603 | RREF | RESISTOR, European symbol | P10KDBCT-ND |  | Panasonic | ERA-3AEB103V |  |  | 10k
1 | 10k | THERMISTOR10K | R0603 | THERM | Thermistor | 490-16279-1-ND |  | Murata | NCU18XH103F60RB
1 | 10uF | C-EU10UFC0805 | C0805 | C11 | CAPACITOR, European symbol | 490-6473-6-ND |  | Murata | GRM21BR61C106KE15K
1 | 1uF | C-EU1UFC0603 | C0603 | C5 | CAPACITOR, European symbol | 490-10479-1-ND |  | Murata | GRM188R61C105KA12D
2 | 4.7k | R-EU_4.7KR0402 | R0402 | R1, R2 | RESISTOR, European symbol | 311-4.7KJRCT-ND |  | Yageo | RC0402JR-074K7L |  |  | 4.7k
1 | AVRISP-6 | AVRISP-6 | AVRISP | ISP1 | AVR ISP HEADER
1 | DMG3404 | MOSFET-NCH-DMG3404L | SOT23-3 | Q2 | N-channel MOSFETs | DMG3404L-7DICT-ND |  | Diodes Incorporated | DMG3404L-7 |  | DMG3404
1 | JUMPER-SMT_3_1-NC_PASTE_SILK | JUMPER-SMT_3_1-NC_PASTE_SILK | SMT-JUMPER_3_1-NC_PASTE_SILK | JP1 | Normally closed solder jumper (1 of 2 connections)
1 | MAX6070AAUT18 | MAX6070AAUT18 | SOT23-6L | U6 | MAX6070 Low Noise high precision voltage referance | MAX6070BAUT18+TCT-ND |  | Maxim | MAX6070BAUT18+T
1 | MCP3421A3 | MCP3421A3 | SOT23-6L | U4 | MCP342* - Sigma Delta ADC | MCP3421A3T-E/CHCT-ND | MCP3421 | Microchip | MCP3421A3T-E/CH
1 | MS5803-14BA | MS5803-14BA | MS5803 | U1 |  | 223-1625-5-ND |  | TE | MS580305BA01-00 | IC-12111
1 | OSHW-LOGOM | OSHW-LOGOM | OSHW-LOGO-M | LOGO1 | Open-Source Hardware (OSHW) Logo
1 | POGO_PAD | POGO_PAD | POGO_PAD | U$12 | POGO Pad
1 | SN65HVD33RHL | SN65HVD33RHL | VQFN-20_POWER | U2 | SN65HVD33 - Full Duplex RS-485 Tranciver, with output enable | 296-24087-1-ND |  | TI | SN65HVD33RHLR
1 | TPS79733 | TPS79733 | DCK_R-PDSO-G5 | U5 | TPS797* - Ultra Low Power Low Dropout Linear Regulator | 296-11990-1-ND |  | TI | TPS79733DCKR
1 | TXS0102DQM | TXS0102DQM | DQM_R-PX2SON-N8 | U7 | TXS0102 - 2 Channel Bidirectional Voltage Level Translator | 296-28435-1-ND |  | TI | TXS0102DQMR

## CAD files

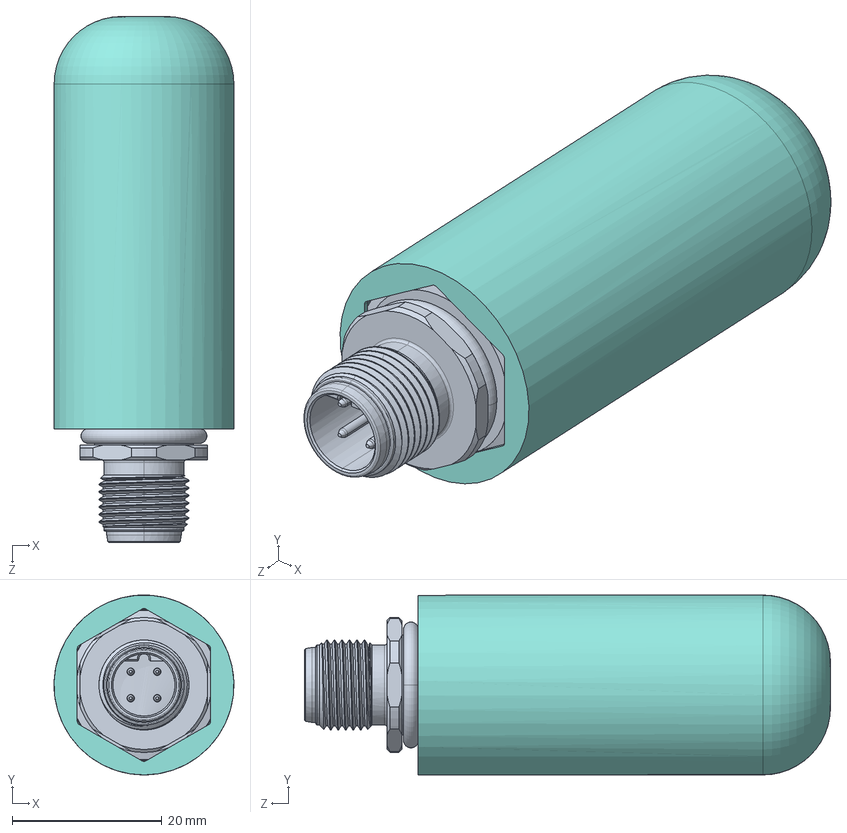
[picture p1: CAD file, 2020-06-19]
Documentation/3D Model/Walrus_HardMount_Assembly.SLDASM
24.0 x 24.0 x 70.1 mm
c-t4132412041-000-a-3d.stp
c-ms580302ba01-00-a-3d
Board.step
MS580302BA.step
0.1uF.step x 6
10k.step x 6
POGO_PAD.step
1uF.step x 2
SOT23-3.step x 2
2_56.step
AVRISP-6.step
QFN20.step
TXS0102DQM.step
LEDBLUE0603.step
1k.step
SOLDERCUP_CONN_QUAD.step
NS5A4684S.step
SN65HVD72DSOIC.step
MCP9808MSOP.step
LP39883.3VDBV.step
09-Pin-End^929665-09-03_Walrus_HardMount_Assembly
09-Pin-Middle^929665-09-03_Walrus_HardMount_Assembly x 2
Epoxy_housing
Snap around hex housing
0.25inch Brass Pipe screen

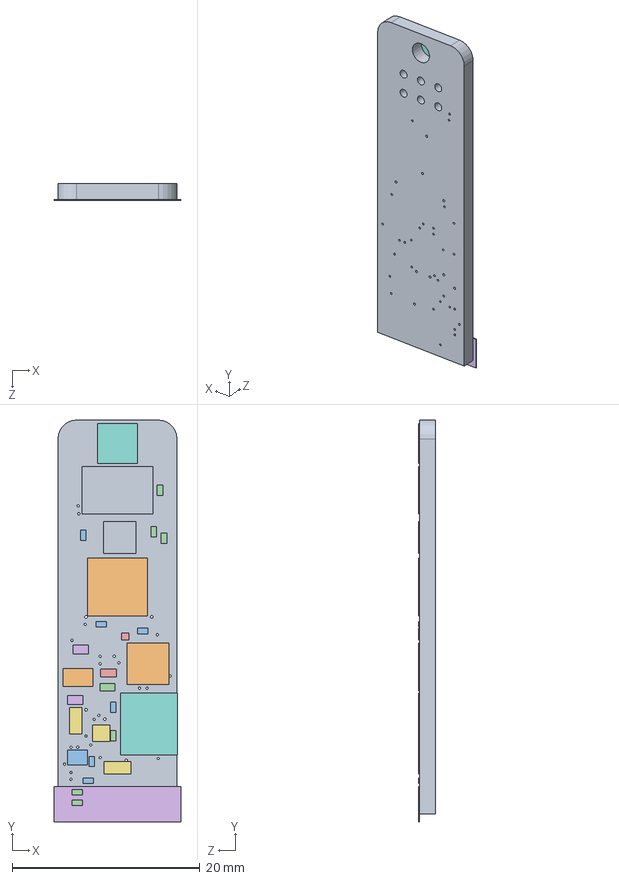
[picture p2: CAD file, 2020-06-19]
Documentation/3D Model/TPDH-Walrus_HardMount.SLDASM
13.5 x 42.9 x 1.77 mm
Board.step
MS580302BA.step
0.1uF.step x 6
10k.step x 6
POGO_PAD.step
1uF.step x 2
SOT23-3.step x 2
2_56.step
AVRISP-6.step
QFN20.step
TXS0102DQM.step
LEDBLUE0603.step
1k.step
SOLDERCUP_CONN_QUAD.step
NS5A4684S.step
SN65HVD72DSOIC.step
MCP9808MSOP.step
LP39883.3VDBV.step

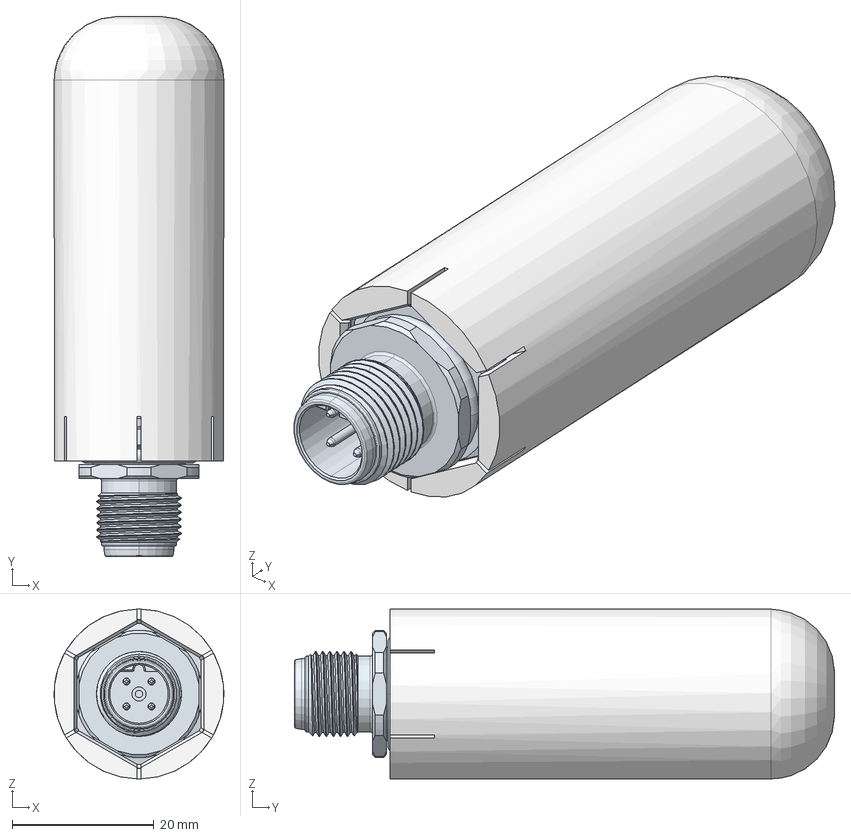
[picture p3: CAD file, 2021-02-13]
3Dprint/HousingHardMount-EpoxyTray/WalrusEnclosure.step
24.0 x 76.3 x 24.0 mm
09-Pin-Middle_1
C-T4132412041-000
AVRISP
WQFN10
R0402 x 6
C0603 x 2
SOT23-3 x 2
Board
SOLDERCUP_CONN_QUAD
C0402 x 6
LED_0603
DQM_R-PX2SON-N8
MS5803
DBV0005A
SO08
QFN20
R0603
POGO_PAD
MSOP_8
C-MS580302BA01-00

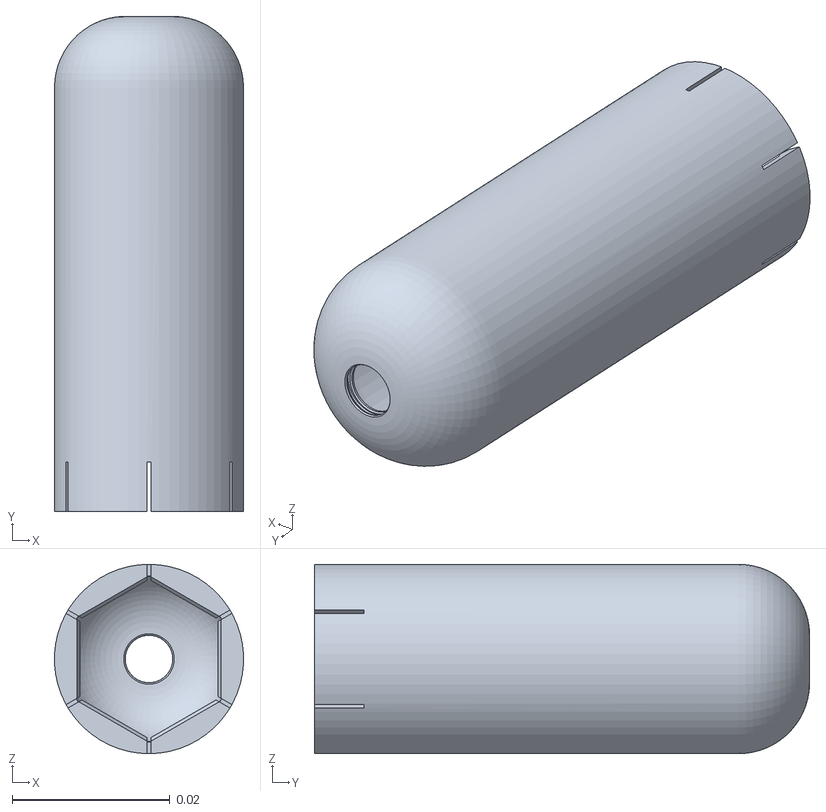
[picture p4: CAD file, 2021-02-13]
3Dprint/HousingHardMount-EpoxyTray/WalrusHardMount_Housing_ExteriorCylinder.stl
0.024 x 0.0628 x 0.024

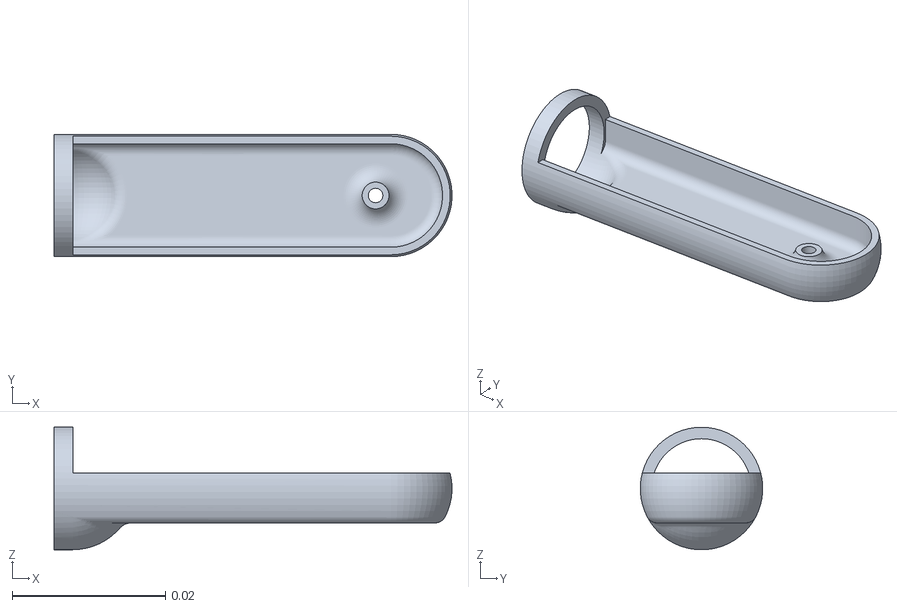
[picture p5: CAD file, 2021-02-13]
3Dprint/HousingHardMount-EpoxyTray/WalrusHardMount_Housing_EpoxyTray.stl
0.052 x 0.016 x 0.016

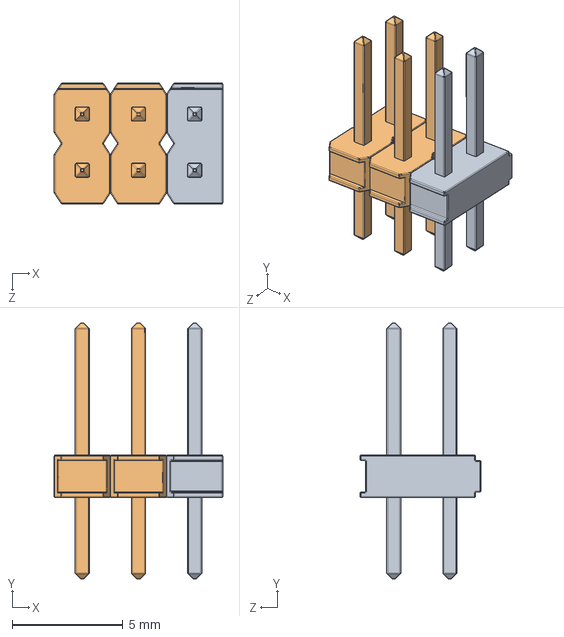
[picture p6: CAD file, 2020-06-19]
Documentation/3D Model/929665-09-03^Walrus_HardMount_Assembly.SLDASM
7.62 x 11.6 x 5.46 mm
09-Pin-End^929665-09-03_Walrus_HardMount_Assembly
09-Pin-Middle^929665-09-03_Walrus_HardMount_Assembly x 2

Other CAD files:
3Dprint/HousingLargePTH/Walrus_Box_Body.SLDPRT
3Dprint/StencilMount_Walrus.STL
Documentation/3D Model/Snap around hex housing.SLDPRT
3Dprint/HousingLargePTH/Walrus_Box_Lid.SLDPRT
Documentation/3D Model/0.25inch Brass Pipe screen.SLDPRT
Documentation/3D Model/Housing1.SLDPRT
Documentation/3D Model/Epoxy_housing.SLDPRT
Documentation/3D Model/c-t4132412041-000-a-3d.stp.SLDPRT
Documentation/3D Model/c-ms580302ba01-00-a-3d.SLDPRT
3Dprint/HousingHardMount-LargeCylinderConfCoat/Walrus_ScrewHousing_Cap_Thread.SLDPRT
3Dprint/HousingHardMount-LargeCylinderConfCoat/Walrus_ScrewHousing.SLDPRT
3Dprint/HousingHardMount-LargeCylinderConfCoat/Walrus_ScrewHousing_Cap.SLDPRT
3Dprint/HousingHardMount-LargeCylinderConfCoat/Walrus_ScrewHousing.STL
3Dprint/HousingHardMount-LargeCylinderConfCoat/Walrus_ScrewHousing_Body_Thread.SLDPRT
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

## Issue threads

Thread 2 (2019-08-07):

Output MUX Overvoltage

bschulz1701, 2019-08-07:
Specific to Hard Mount device
### Problem:
Output MUX (`U8`) is powered by the core 3.3v rail, however the I2C inputs (`SDA_HV`, `SCL_HV`) are level shifted to the input voltage (up to 5v), which would result in the inputs to the MUX being 1.7v higher than Vcc, which is well outside of the absolute maximum operating spec

### Potential Solution:
Ideally, the MUX would simply be powered off the input voltage (`Vin+`), this would guarantee that the input is never greater than Vcc, even if the inputs are shifted up to the 5v input.

#### To Verify/Test:
- Must make sure at this voltage that 3.3v logic will still control the device appropriately
- Investigate excess current draw for the device when operating with IN1/2 at 3.3v and Vcc at 5v

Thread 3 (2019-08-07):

Switch I2C Output Connections

bschulz1701, 2019-08-07:
### Problem:
External I2C connections (into cable) are not consistent with others using the same cable ([Project Haar](https://github.com/NorthernWidget-Skunkworks/Project-Haar))

### Potential Solution:
Change the SDA/SCL configuration to match Haar

awickert, 2021-02-13:
@bschulz1701: I believe that this cable design is now consistent with our other designs.

However, if we use the AlphaWire cable, the pinout wire colors are unintuitive. I believe that we're approaching the go-or-no-go moment for deciding whether to change all HardMount pinouts (for now: this and https://github.com/NorthernWidget-Skunkworks/Project-Haar). My vote would be:
* YES to change
* to increment the version numbers to reflect this change
* To use the Brother labelmaker to include wraparound able labels with the pinout noted; these should be placed at a far enough distance from the wires to the loggers that they do not interfere with the cable gland.

What is your opinion here?

awickert, 2021-02-13:
A bit more information:

**Current pinout:**
| **Color** | **Connection** |
|-----------|----------------|
| Brown     | V+ (3.3-5.5 V) |
| White     | GND            |
| Black     | SDA            |
| Blue      | SCL            |

**Proposed pinout:**
| **Color** | **Connection** |
|-----------|----------------|
| White     | V+ (3.3-5.5 V) |
| Black     | GND            |
| Brown     | SDA            |
| Blue      | SCL            |

Linked issue in Haar repository: https://github.com/NorthernWidget-Skunkworks/Project-Haar/issues/6

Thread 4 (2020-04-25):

3D print enclosure for the HardMount design

awickert, 2020-04-25:
I know that @bschulz1701 had been working on a HardMount enclosure but was having difficulties with the epoxy pour-over because of the height of the plug vs. the height of the pressure transducer. We then discussed a screw-on enclosure with a conformal coating and/or just using wires soldered to the SMD pads. What is our final plan? And if there is any CAD work to be done, I sadly don't know SolidWorks, so would have to ask @bschulz1701 or @superchap123 to do it.

superchap123, 2020-06-19:
Rev A hard mount assembly put into documentation (maybe not the best place for this, also used GitHub desktop for this and brought over some unintended files it seems, will fix later).  Design is for use with T4132412041-000 connector or like TE M12 panel mount connector. Could use some refinements/additions to the models.  Need to add 2-56 screw to assembly.  Add an ISP pin protector.  Not sure about the current dimensions for capturing the M16 panel nut, thinking it would be difficult to press on in the current state but might be OK.  Real-world tests would be helpful.  @bschulz1701 or @awickert evaluate if able.
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

awickert, 2020-06-19:
@superchap123 I did a little happy dance around the cabin when I saw this. It looks fantastic and is now in the README.

I have a couple thoughts and will open other "Issues" to discuss.

awickert, 2020-06-19:
Reopening this with a question for @superchap123 or somebody: How do we get the epoxy to the bottom of the board in the tray?

superchap123, 2020-06-19:
I had started the design with the intension of clipping onto the board and the screw hole would have done the job of getting the potting compound to the bottom side but I started leaning in favor of the screw again.  My thought was to round off the end of the tray more or less matching the dome profile of the 3D printed housing which would leave a gap at the end but I had not made those revisions yet.  I am not sure how well the stuff flows and maybe the current gap would be enough but probably not and increasing the length a bit to make this easier seems worth it.  Since it is not going to fit through an M16x1.5 opening we have some room to grow in the width if we would rather as well.  I also should need to change the screw protrusion on the bottom side into something better suited for printing.  Currently, this will need to print standing up and not sure how well that will go.  Might need to go thicker.

awickert, 2020-06-20:
I was thinking of the screw hole too but then saw that you were asking about a 2-56 screw!

Bobby's standing-up prints on the Prusa have gone pretty well, but yeah, a little extra thickness can't hurt.

Sounds like you have the right ideas in mind. I plan to program a Walrus soon, and then will drop it off with you for testing and sizing.

superchap123, 2020-06-22:
I think I am going to remake the models in Onset which can be used for free but all models will be released under an open source licence.  It should also be very easy to collaborate and access the files as it is browser based software.

Chad Sandell

________________________________
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

awickert, 2020-06-22:
You mean Onshape?
https://www.onshape.com/products/free
Sure; just send the link! Maybe I'll finally learn some 3D CAD.

superchap123, 2020-06-22:
I had started the design with the intension of clipping onto the board and the screw hole would have done the job of getting the potting compound to the bottom side but I started leaning in favor of the screw again.  My thought was to round off the end of the tray more or less matching the dome profile of the 3D printed housing which would leave a gap at the end but I had not made those revisions yet.  I am not sure how well the stuff flows and maybe the current gap would be enough but probably not and increasing the length a bit to make this easier seems worth it.  Since it is not going to fit through an M16x1.5 opening we have some room to grow in the width if we would rather as well.  I also should need to change the screw protrusion on the bottom side into something better suited for printing.  Currently, this will need to print standing up and not sure how well that will go.  Might need to go thicker.

superchap123, 2020-07-04:
Happy 4th!  Finally got the models remade and updated in Onshape.  I need to get the physical parts from you and start printing stuff.

Chad Sandell

________________________________
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

awickert, 2020-07-04:
Excellent news and happy 4th! I'll get in touch about swinging by and dropping off the boards.

awickert, 2021-02-13:
@superchap123 completed his updates, and I have just updated the repo to include the 3D print and full assembly files.
15a6ea1ceea464b84c4a1b21669ceb5cb8cb5855

Closed 2021-02-13.

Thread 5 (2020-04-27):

BoM pressure transducer model change

awickert, 2020-04-27:
The BoM line for the pressure transducer is:

"1","MS5803-14BA","MS5803-14BA","MS5803","U1","","223-1625-5-ND","","TE","MS580305BA01-00","IC-12111","","",

This mentions the 14BA and the 05BA. However, aren't we using the **02BA** for most of our work? @bschulz1701, could you verify? If so, let's update, as this seems like a good way to send along the wrong part number to a manufacturer.

awickert, 2020-05-25:
@bschulz1701 made this change.

Closed 2020-05-25.

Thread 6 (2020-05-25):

Upload I2C firmware for HardMount board

awickert, 2020-05-25:
Update the README when this is finished.
@bschulz1701: You mentioned that you probably have this on another computer (maybe in lab)? Tag this for later if we just need to wait to get access to it again.

awickert, 2021-02-13:
This was completed a while ago now!
https://github.com/NorthernWidget-Skunkworks/Project-Walrus/tree/master/Firmware
The README was updated just now: 9afd3ad479141ef3367964798bb032d5c0a1a43f

Closed 2021-02-13.

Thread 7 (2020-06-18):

Housing dimensions

awickert, 2020-06-18:
From @superchap123 via email:

"I want to keep the potted sensor narrow enough to fit through an M16 nut but if we want the potting compound to seal the sides of the FR4, that will be rather tricky.  Do we care about the potting material sealing up the sides of the FR4?  We can pot the top/bottom and that should be enough to keep water away from the edges as long as 3D print stays watertight.  If we want full-encapsulation it would be nice if the sensor width was reduced slightly but I suppose the board design is fixed for now correct?  I have alternative ideas to nicely mate a housing to the connector with this sensor that we can use."

awickert, 2020-06-18:
Short version: Make it fit an M20 instead and/or look into Bobby's simpler design?

It looks like you're thinking of a much more sophisticated encapsulation than what @bschulz1701 designed here!
https://github.com/NorthernWidget-Skunkworks/Project-Walrus/tree/master/3Dprint/HousingLargePTH

The Walrus board might be able to be made a bit narrower, but is about as narrow as can reasonably be managed. We could probably try to make it longer/skinnier, which would require a redesign and may require a 4-layer board. I don't think that we currently have the engineer-power to do that.

I am not sure of the waterproofing characteristics of the FR4. I wouldn't count on the 3D print alone staying watertight.

Unlike the [TP-DownHole](https://github.com/NorthernWidget/TP-DownHole), this wasn't designed to be tiny. Maybe we could aim for an M20 nut instead?

awickert, 2021-02-13:
Instead of redesigning the board, @superchap123 built a plastic-flex nut grabber. This is a successful alternative solution (15a6ea1ceea464b84c4a1b21669ceb5cb8cb5855).

Closed 2021-02-13.

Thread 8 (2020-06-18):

Housing size / MEMS membrane access

awickert, 2020-06-18:
From email from @superchap123

"Do we have a maximum size that we want to consider to limit contaminants reaching the sensor membrane?  Are we concerned about this?"

awickert, 2020-06-18:
I have no specific housing size in mind. The most likely damage to the sensor would be from sediment; having some kind of screen would be good. Will take some balancing: finer screens out more particles; coarser ensures that pressure can be transmitted quickly enough that the sensor readings are accurate.

To answer more directly, I don't think that size should matter.

One related thought: we should see if we can isolate the membrane as much as possible from water with appreciable velocity. This way, the unit could be used outside of a stilling well. (I know I've mentioned this over email, but thought good to put here too; can open a separate Issue.)

awickert, 2021-02-13:
@superchap123 created a design that may not perfectly isolate sediment (we will have to test) but does a good job of removing the transducer from the effects of the surrounding velocity, effectively giving it its own self-contained stilling well. This has not yet been tested in moving water.
15a6ea1ceea464b84c4a1b21669ceb5cb8cb5855

Closed 2021-02-13.

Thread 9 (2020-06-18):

All 3D-printed parts for worldwide accessibility?

awickert, 2020-06-18:
From email from @superchap123:

"Do we want to avoid purchased parts for housings and rely exclusively on 3d printed parts?    Thinking about accessibility around the world but I am not against incorporating purchased parts in the housings."

awickert, 2020-06-18:
This is a good point, and one that I hadn't thought of.

All 3D-printed parts for global use is what 3D-PAWS did: https://www.icdp.ucar.edu/core-programs/3dpaws/

If all 3D parts are possible, great! However, our plug is a specialized manufactured part too, so I would not stress this so much that it impedes progress.

awickert, 2021-02-13:
@superchap123 designed all of the enclosure parts to be 3D printed, so that's a start (15a6ea1ceea464b84c4a1b21669ceb5cb8cb5855). Closing now.

Closed 2021-02-13.

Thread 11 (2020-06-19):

Alternative external housing

awickert, 2020-06-19:
Not urgent! Just inspired and thinking.

Chad's 3D-printed housing made me start thinking about the old TP-DownHole housing and how we used a sintered muffler as a filter. This also acted as ballast to help keep the sensor facing down and at the bottom. Perhaps we could use an M12 to <some common size> bushing on the plug, and then attach it to a metal cylinder and muffler.

awickert, 2021-02-13:
@superchap123 made a new design seems to work well. I think that we could consider ways to make this kind of housing work instead of his external 3D-printed nut grabber. Closing this for now since the main problem is solved; can revisit if it it seems like a good option.

Closed 2021-02-13.

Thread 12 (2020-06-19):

Hole to release trapped air

awickert, 2020-06-19:
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

I like the screen on the bottom to help any sediment that enters the housing to leave. I think we will want a second one on the end near the screw-on cable plug to make sure that no large air bubble can be trapped inside the sensor, thereby affecting its readings. This could be sealed with a screen too, and may be quite small in the 3D print.

awickert, 2021-02-13:
@superchap123's new design (15a6ea1ceea464b84c4a1b21669ceb5cb8cb5855) includes a device to clasp the nut that uses a set of gaps in the plastic; these will also be air-escape holes. Problem solved.

Closed 2021-02-13.

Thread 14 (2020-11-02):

I2C firmware will never sample

SRGDamia1, 2020-11-02:
As far as I can tell, the I2C firmware will never take a sample.

The timeout is re-set in the very beginning of every loop:
https://github.com/NorthernWidget-Skunkworks/Project-Walrus/blob/b5d9cc1fdfe2cf16fb5048a1f9ff0b27253c3a94/Firmware/Walrus_I2C_5BA/Walrus_I2C_5BA.ino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

Then the timeout is checked immediately after the conditional coding:
https://github.com/NorthernWidget-Skunkworks/Project-Walrus/blob/b5d9cc1fdfe2cf16fb5048a1f9ff0b27253c3a94/Firmware/Walrus_I2C_5BA/Walrus_I2C_5BA.ino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

But the condition to set `StartSample = true` within the loop will **_never_** be true because the timeout value was only set a few lines before within the same loop.

So it should sample one time, and then never again.

SRGDamia1, 2020-11-02:
Ignore this. I didn't understand what was going on.

Closed 2020-11-02.

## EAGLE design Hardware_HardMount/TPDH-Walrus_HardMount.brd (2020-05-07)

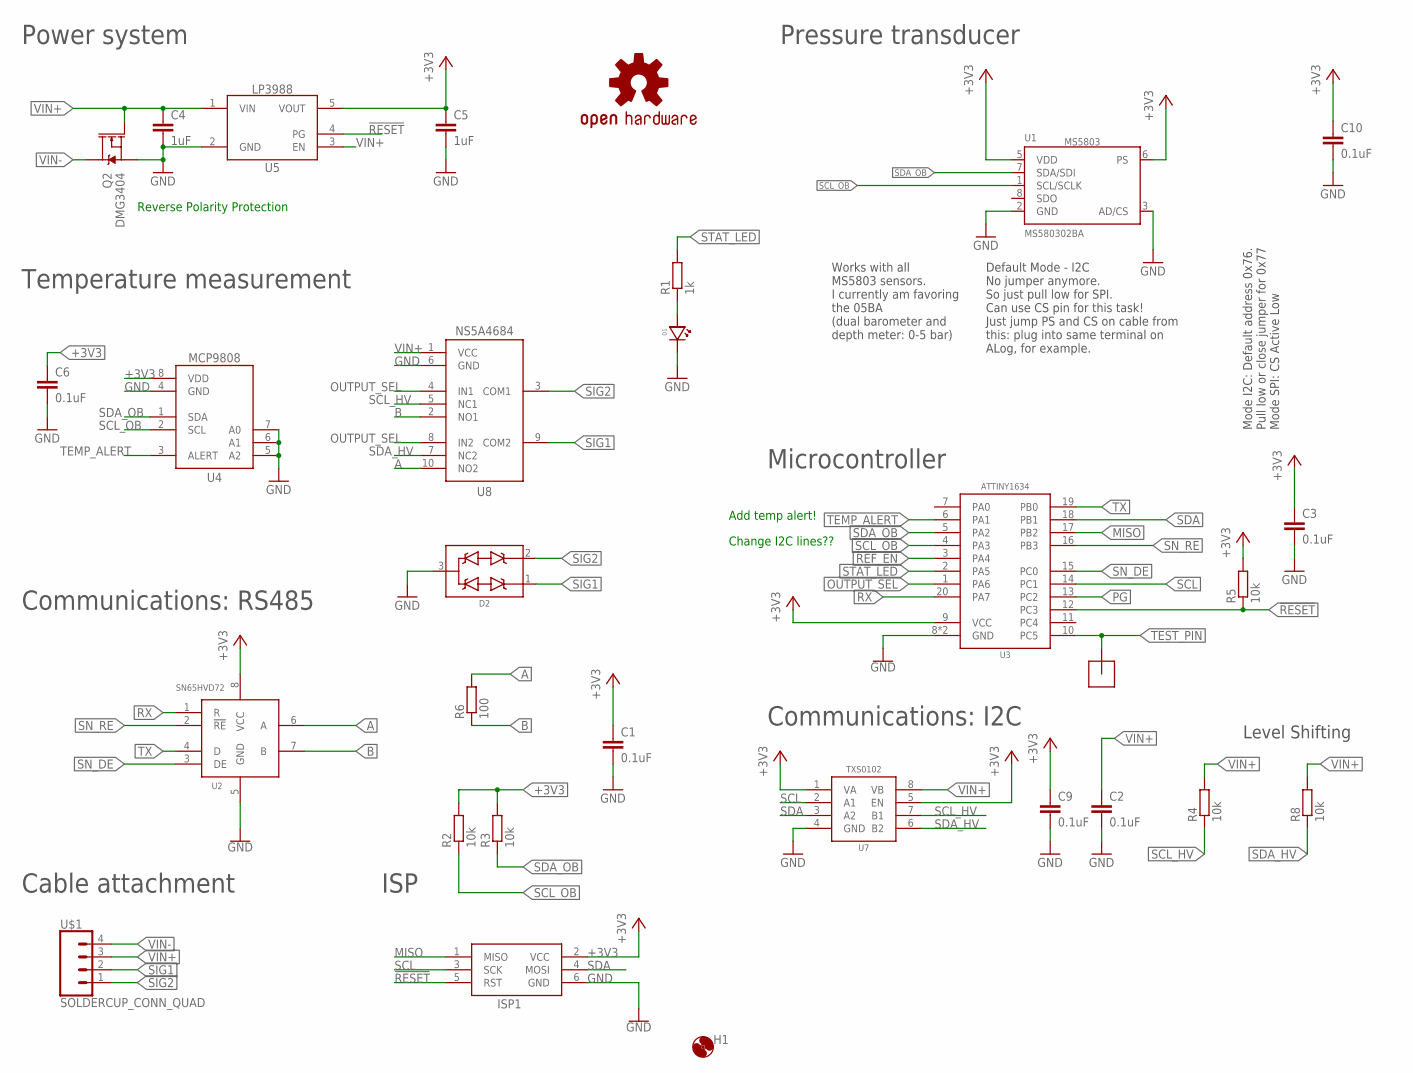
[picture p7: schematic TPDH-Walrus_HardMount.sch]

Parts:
C1, C2, C3, C6, C9, C10: 0.1uF; C0402
C4, C5: 1uF; C0603
D1: LEDBLUE0603; LED_0603
D2: TVSSM712; SOT23-3
H1: MOUNTING_HOLE2_NP; 2_56
ISP1: AVRISP-6; AVRISP
LOGO1: OSHW-LOGOM; OSHW-LOGO-M
Q2: DMG3404; SOT23-3
R1: 1k; R0603
R2, R3, R4, R5, R8: 10k; R0402
R6: 100; R0402
U1: MS580302BA; MS5803
U2: SN65HVD72DSOIC; SO08
U3: ATTINY1634QFN; QFN20
U4: MCP9808MSOP; MSOP_8
U5: LP39883.3VDBV; DBV0005A
U7: TXS0102DQM; DQM_R-PX2SON-N8
U8: NS5A4684S; WQFN10
U$1: SOLDERCUP_CONN_QUAD
U$12: POGO_PAD

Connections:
!RESET: ISP1.5 (RST), R5.1, U3.12 (PC3), U5.4 (PG)
+3V3: C1.1, C3.1, C5.1, C6.1, C9.1, C10.1, ISP1.2 (VCC), R2.2, R3.2, R5.2, U1.5 (VDD), U1.6 (PS), U2.8 (VCC), U3.9 (VCC), U4.8 (VDD), U5.5 (VOUT), U7.1 (VA), U7.5 (EN)
A: R6.2, U2.6 (A), U8.10 (NO2)
B: R6.1, U2.7 (B), U8.2 (NO1)
GND: C1.2, C2.2, C3.2, C4.2, C5.2, C6.2, C9.2, C10.2, D1.CATHODE, D2.3 (COM), ISP1.6 (GND), Q2.2 (S), U1.2 (GND), U1.3 (AD/CS), U2.5 (GND), U3.8 (GND), U3.EP (GND), U4.4 (GND), U4.5 (A2), U4.6 (A1), U4.7 (A0), U5.2 (GND), U7.4 (GND), U8.6 (GND)
MISO: ISP1.1 (MISO), U3.17 (PB2)
unnamed: D1.ANODE, R1.1
OUTPUT_SEL: U3.1 (PA6), U8.4 (IN1), U8.8 (IN2)
PG: U3.13 (PC2)
REF_EN: U3.3 (PA4)
RX: U2.1 (R), U3.20 (PA7)
SCL: ISP1.3 (SCK), U3.14 (PC1), U7.2 (A1)
SCL_HV: R4.1, U7.7 (B1), U8.5 (NC1)
SCL_OB: R2.1, U1.1 (SCL/SCLK), U3.4 (PA3), U4.2 (SCL)
SDA: ISP1.4 (MOSI), U3.18 (PB1), U7.3 (A2)
SDA_HV: R8.1, U7.6 (B2), U8.7 (NC2)
SDA_OB: R3.1, U1.7 (SDA/SDI), U3.5 (PA2), U4.1 (SDA)
SIG1: D2.1 (D1), U8.9 (COM2), U$1.2
SIG2: D2.2 (D2), U8.3 (COM1), U$1.1
SN_DE: U2.3 (DE), U3.15 (PC0)
SN_RE: U2.2 (!RE), U3.16 (PB3)
STAT_LED: R1.2, U3.2 (PA5)
TEMP_ALERT: U3.6 (PA1), U4.3 (ALERT)
TEST_PIN: U3.10 (PC5), U$12.P$1
TX: U2.4 (D), U3.19 (PB0)
VIN+: C2.1, C4.1, Q2.1 (G), R4.2, R8.2, U5.1 (VIN), U5.3 (EN), U7.8 (VB), U8.1 (VCC), U$1.3
VIN-: Q2.3 (D), U$1.4

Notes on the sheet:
Default Mode - I2C No jumper anymore. So just pull low for SPI. Can use CS pin for this task! Just jump PS and CS on cable from this: plug into same terminal on ALog, for example.
Mode I2C: Default address 0x76. Pull low or close jumper for 0x77 Mode SPI: CS Active Low
Works with all MS5803 sensors. I currently am favoring the 05BA (dual barometer and depth meter: 0-5 bar)
Reverse Polarity Protection
Level Shifting
Pressure transducer
Cable attachment
Communications: I2C
ISP
Communications: RS485
Temperature measurement
Power system
Microcontroller
Change I2C lines??
Add temp alert!

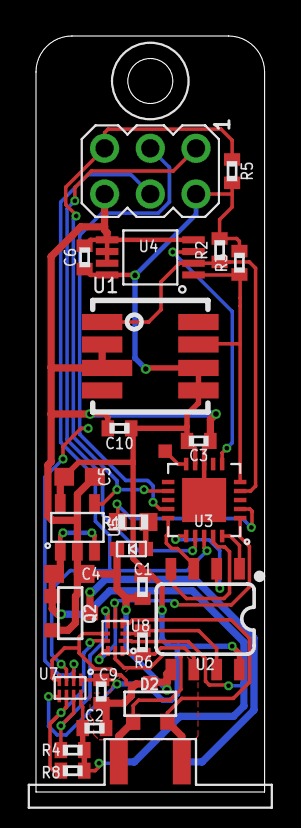
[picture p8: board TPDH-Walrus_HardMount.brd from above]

Board: 2 copper layers, 12.7 x 42.0 mm, 30 parts (1 on the bottom side), 25 nets.

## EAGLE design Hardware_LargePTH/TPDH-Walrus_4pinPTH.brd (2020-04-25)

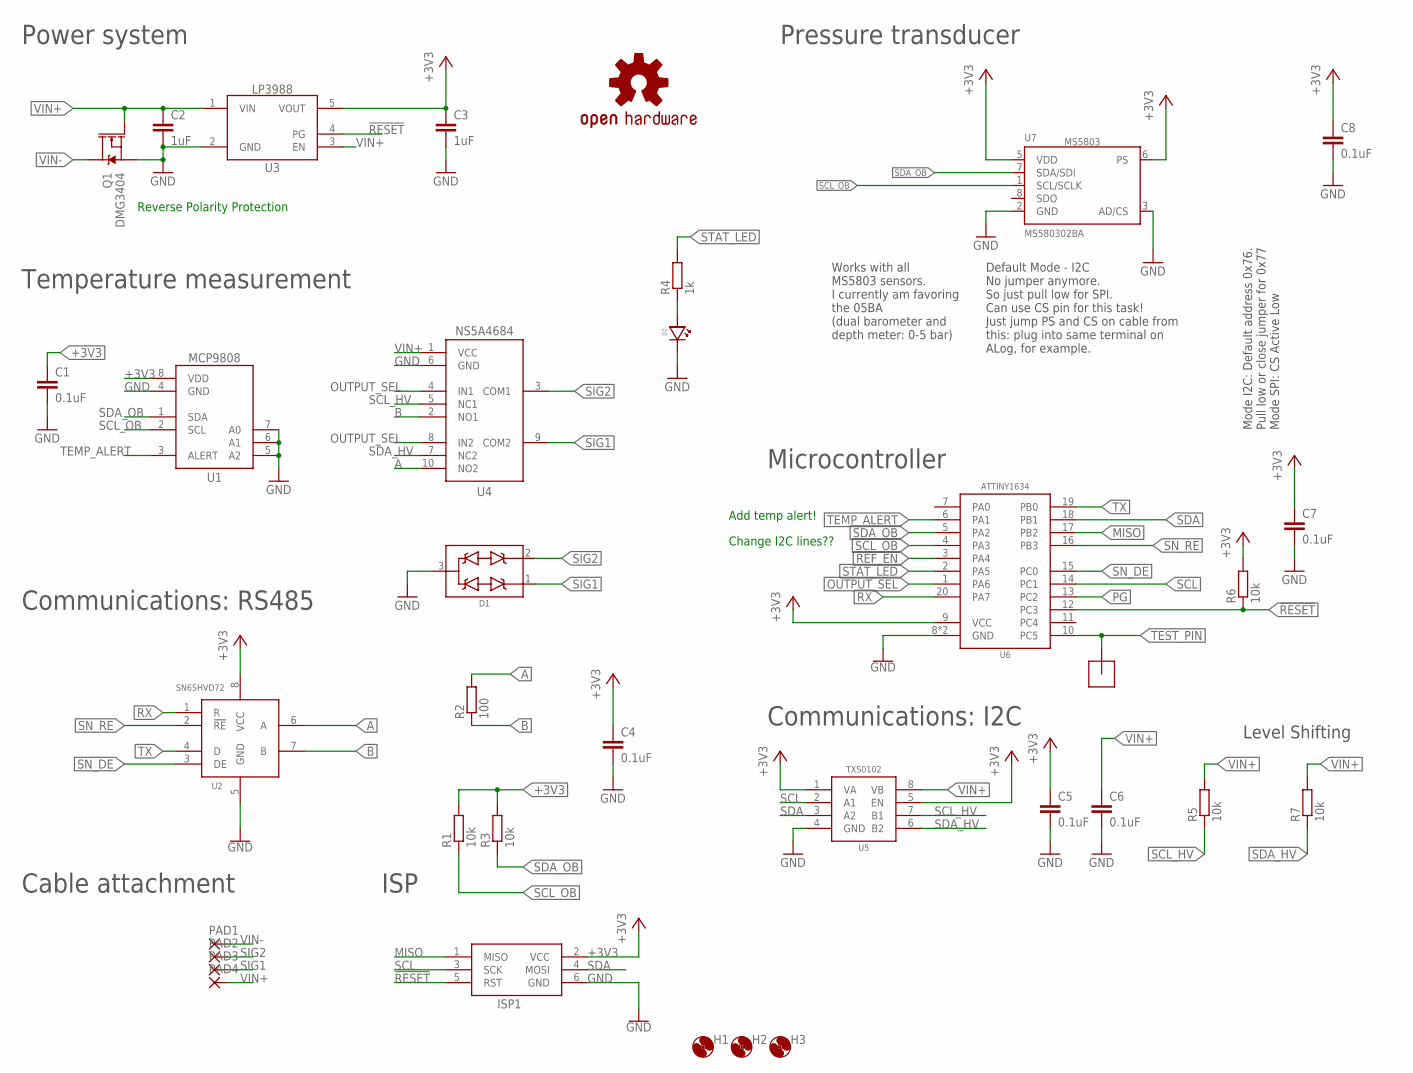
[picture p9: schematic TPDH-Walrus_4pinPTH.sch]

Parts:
C1, C4, C5, C6, C7, C8: 0.1uF; C0402
C2, C3: 1uF; C0603
D1: TVSSM712; SOT23-3
D2: LEDBLUE0603; LED_0603
H1, H2, H3: MOUNTING_HOLE2_NP; 2_56
ISP1: AVRISP-6; AVRISP
LOGO1: OSHW-LOGOM; OSHW-LOGO-M
PAD1, PAD2, PAD3, PAD4: PAD1.1MM; 2,54/1,1
Q1: DMG3404; SOT23-3
R1, R3, R5, R6, R7: 10k; R0402
R2: 100; R0402
R4: 1k; R0603
TP1: POGO_PAD
U1: MCP9808MSOP; MSOP_8
U2: SN65HVD72DSOIC; SO08
U3: LP39883.3VDBV; DBV0005A
U4: NS5A4684S; WQFN10
U5: TXS0102DQM; DQM_R-PX2SON-N8
U6: ATTINY1634QFN; QFN20
U7: MS580302BA; MS5803; MPN MS580305BA01-00; DIGIKEY 223-1625-5-ND

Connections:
!RESET: ISP1.5 (RST), R6.1, U3.4 (PG), U6.12 (PC3)
+3V3: C1.1, C3.1, C4.1, C5.1, C7.1, C8.1, ISP1.2 (VCC), R1.2, R3.2, R6.2, U1.8 (VDD), U2.8 (VCC), U3.5 (VOUT), U5.1 (VA), U5.5 (EN), U6.9 (VCC), U7.5 (VDD), U7.6 (PS)
A: R2.2, U2.6 (A), U4.10 (NO2)
B: R2.1, U2.7 (B), U4.2 (NO1)
GND: C1.2, C2.2, C3.2, C4.2, C5.2, C6.2, C7.2, C8.2, D1.3 (COM), D2.CATHODE, ISP1.6 (GND), Q1.2 (S), U1.4 (GND), U1.5 (A2), U1.6 (A1), U1.7 (A0), U2.5 (GND), U3.2 (GND), U4.6 (GND), U5.4 (GND), U6.8 (GND), U6.EP (GND), U7.2 (GND), U7.3 (AD/CS)
MISO: ISP1.1 (MISO), U6.17 (PB2)
unnamed: D2.ANODE, R4.1
OUTPUT_SEL: U4.4 (IN1), U4.8 (IN2), U6.1 (PA6)
PG: U6.13 (PC2)
REF_EN: U6.3 (PA4)
RX: U2.1 (R), U6.20 (PA7)
SCL: ISP1.3 (SCK), U5.2 (A1), U6.14 (PC1)
SCL_HV: R5.1, U4.5 (NC1), U5.7 (B1)
SCL_OB: R1.1, U1.2 (SCL), U6.4 (PA3), U7.1 (SCL/SCLK)
SDA: ISP1.4 (MOSI), U5.3 (A2), U6.18 (PB1)
SDA_HV: R7.1, U4.7 (NC2), U5.6 (B2)
SDA_OB: R3.1, U1.1 (SDA), U6.5 (PA2), U7.7 (SDA/SDI)
SIG1: D1.1 (D1), PAD3.1, U4.9 (COM2)
SIG2: D1.2 (D2), PAD2.1, U4.3 (COM1)
SN_DE: U2.3 (DE), U6.15 (PC0)
SN_RE: U2.2 (!RE), U6.16 (PB3)
STAT_LED: R4.2, U6.2 (PA5)
TEMP_ALERT: U1.3 (ALERT), U6.6 (PA1)
TEST_PIN: TP1.P$1, U6.10 (PC5)
TX: U2.4 (D), U6.19 (PB0)
VIN+: C2.1, C6.1, PAD4.1, Q1.1 (G), R5.2, R7.2, U3.1 (VIN), U3.3 (EN), U4.1 (VCC), U5.8 (VB)
VIN-: PAD1.1, Q1.3 (D)

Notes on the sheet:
Default Mode - I2C No jumper anymore. So just pull low for SPI. Can use CS pin for this task! Just jump PS and CS on cable from this: plug into same terminal on ALog, for example.
Mode I2C: Default address 0x76. Pull low or close jumper for 0x77 Mode SPI: CS Active Low
Works with all MS5803 sensors. I currently am favoring the 05BA (dual barometer and depth meter: 0-5 bar)
Reverse Polarity Protection
Level Shifting
Pressure transducer
Cable attachment
Communications: I2C
ISP
Communications: RS485
Temperature measurement
Power system
Microcontroller
Change I2C lines??
Add temp alert!

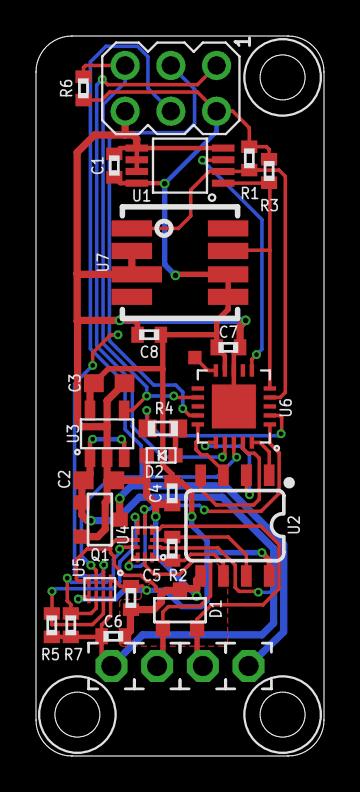
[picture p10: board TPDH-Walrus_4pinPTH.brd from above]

Board: 2 copper layers, 16.0 x 40.0 mm, 35 parts (1 on the bottom side), 25 nets.

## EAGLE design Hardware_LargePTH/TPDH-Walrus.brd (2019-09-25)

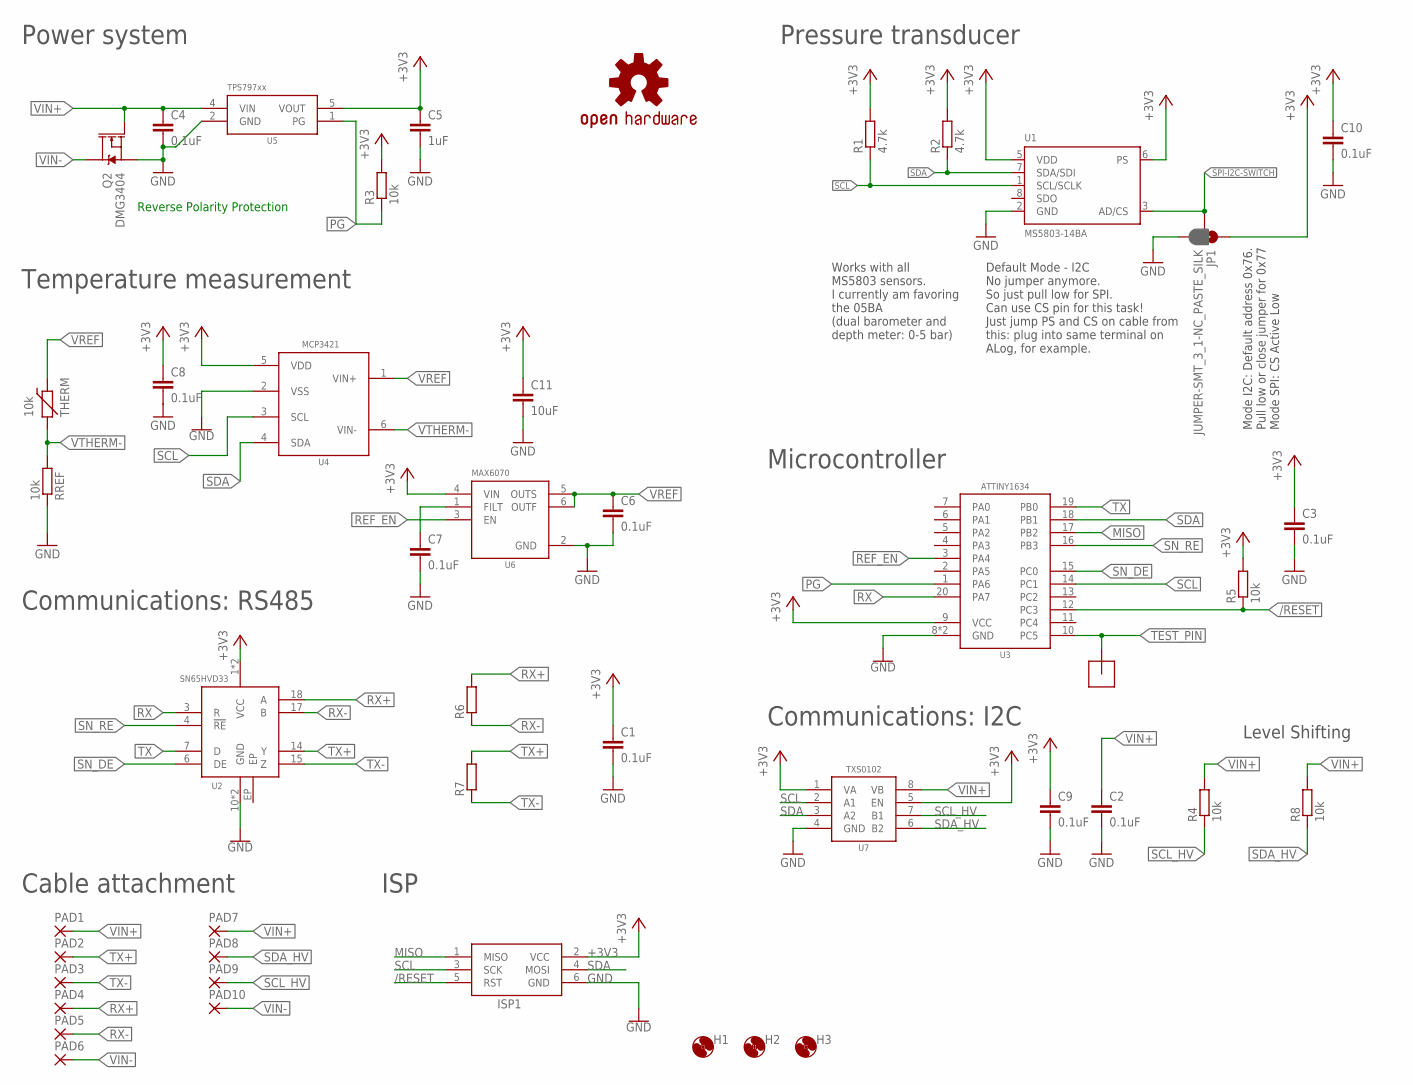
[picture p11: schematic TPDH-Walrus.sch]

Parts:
C1, C2, C3, C4, C6, C7, C8, C9, C10: 0.1uF; C0402
C5: 1uF; C0603
C11: 10uF; C0805
H1, H2, H3: MOUNTING_HOLE2_NP; 2_56
ISP1: AVRISP-6; AVRISP
JP1: JUMPER-SMT_3_1-NC_PASTE_SILK; SMT-JUMPER_3_1-NC_PASTE_SILK
LOGO1: OSHW-LOGOM; OSHW-LOGO-M
PAD1, PAD2, PAD3, PAD4, PAD5, PAD6, PAD7, PAD8, PAD9, PAD10: 2,15/1,0
Q2: DMG3404; SOT23-3
R1, R2: 4.7k; R0402
R3, R4, R5, R8: 10k; R0402
R6, R7: R-EU_100R0402; R0402
RREF: 10k; R0603; MPN ERA-3AEB103V; DIGIKEY P10KDBCT-ND
THERM: 10k; R0603
U1: MS5803-14BA; MS5803; MPN MS580305BA01-00; DIGIKEY 223-1625-5-ND
U2: SN65HVD33RHL; VQFN-20_POWER
U3: ATTINY1634QFN; QFN20
U4: MCP3421A3; SOT23-6L
U5: TPS79733; DCK_R-PDSO-G5
U6: MAX6070AAUT18; SOT23-6L
U7: TXS0102DQM; DQM_R-PX2SON-N8
U$12: POGO_PAD

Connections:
+3V3: C1.1, C3.1, C5.1, C8.1, C9.1, C10.1, C11.1, ISP1.2 (VCC), JP1.1, R1.2, R2.2, R3.2, R5.2, U1.5 (VDD), U1.6 (PS), U2.1 (VCC), U2.20 (VCC), U3.9 (VCC), U4.5 (VDD), U5.5 (VOUT), U6.4 (VIN), U7.1 (VA), U7.5 (EN)
/RESET: ISP1.5 (RST), R5.1, U3.12 (PC3)
GND: C1.2, C2.2, C3.2, C4.2, C5.2, C6.2, C7.2, C8.2, C9.2, C10.2, C11.2, ISP1.6 (GND), JP1.3, Q2.2 (S), RREF.1, U1.2 (GND), U2.10 (GND), U2.11 (GND), U3.8 (GND), U3.EP (GND), U4.2 (VSS), U5.2 (GND), U6.2 (GND), U7.4 (GND)
MISO: ISP1.1 (MISO), U3.17 (PB2)
unnamed: C7.1, U6.1 (FILT)
PG: R3.1, U3.1 (PA6), U5.1 (PG)
REF_EN: U3.3 (PA4), U6.3 (EN)
RX: U2.3 (R), U3.20 (PA7)
RX+: PAD4.1, R6.2, U2.18 (A)
RX-: PAD5.1, R6.1, U2.17 (B)
SCL: ISP1.3 (SCK), R1.1, U1.1 (SCL/SCLK), U3.14 (PC1), U4.3 (SCL), U7.2 (A1)
SCL_HV: PAD9.1, R4.1, U7.7 (B1)
SDA: ISP1.4 (MOSI), R2.1, U1.7 (SDA/SDI), U3.18 (PB1), U4.4 (SDA), U7.3 (A2)
SDA_HV: PAD8.1, R8.1, U7.6 (B2)
SN_DE: U2.6 (DE), U3.15 (PC0)
SN_RE: U2.4 (!RE), U3.16 (PB3)
SPI-I2C-SWITCH: JP1.2, U1.3 (AD/CS)
TEST_PIN: U3.10 (PC5), U$12.P$1
TX: U2.7 (D), U3.19 (PB0)
TX+: PAD2.1, R7.2, U2.14 (Y)
TX-: PAD3.1, R7.1, U2.15 (Z)
VIN+: C2.1, C4.1, PAD1.1, PAD7.1, Q2.1 (G), R4.2, R8.2, U5.4 (VIN), U7.8 (VB)
VIN-: PAD6.1, PAD10.1, Q2.3 (D)
VREF: C6.1, THERM.1 (2), U4.1 (VIN+), U6.5 (OUTS), U6.6 (OUTF)
VTHERM-: RREF.2, THERM.2 (1), U4.6 (VIN-)

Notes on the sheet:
Default Mode - I2C No jumper anymore. So just pull low for SPI. Can use CS pin for this task! Just jump PS and CS on cable from this: plug into same terminal on ALog, for example.
Mode I2C: Default address 0x76. Pull low or close jumper for 0x77 Mode SPI: CS Active Low
Works with all MS5803 sensors. I currently am favoring the 05BA (dual barometer and depth meter: 0-5 bar)
Reverse Polarity Protection
Level Shifting
Pressure transducer
Cable attachment
Communications: I2C
ISP
Communications: RS485
Temperature measurement
Power system
Microcontroller

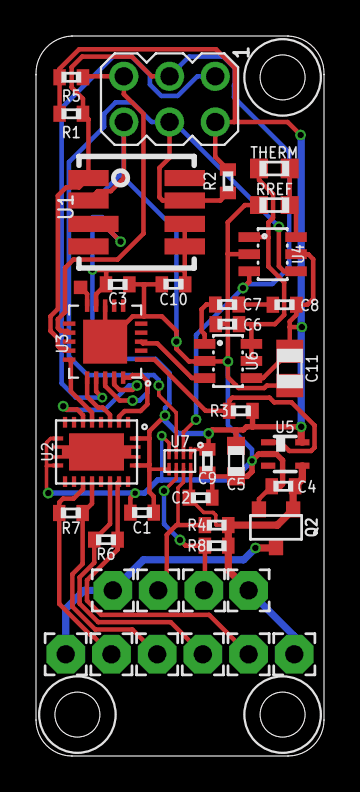
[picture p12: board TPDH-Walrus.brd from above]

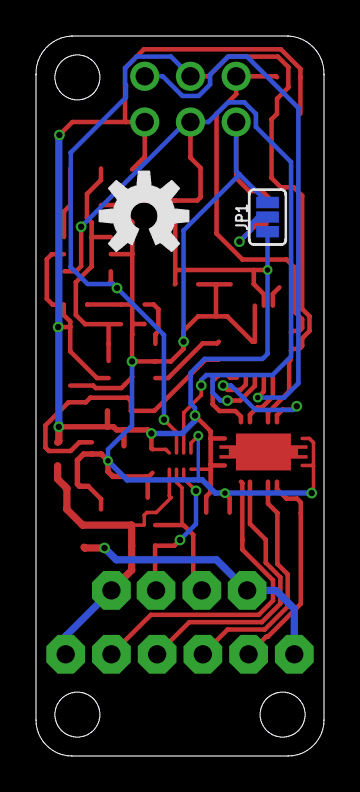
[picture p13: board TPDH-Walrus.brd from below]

Board: 2 copper layers, 16.0 x 40.0 mm, 46 parts (2 on the bottom side), 25 nets.

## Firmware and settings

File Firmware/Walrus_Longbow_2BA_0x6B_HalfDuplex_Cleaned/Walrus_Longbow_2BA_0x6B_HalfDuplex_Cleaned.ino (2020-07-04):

#include <SlowSoftWire.h>
#include <Wire.h>
#include <EEPROM.h>

#define MODEL 0x1201
#define GROUPID 0x0871
#define INDID 0x06
#define FIRMWAREID 0x00

#define CMD_RESET 0x1E // reset command
#define CMD_ADC_READ 0x00 // ADC read command
#define CMD_ADC_CONV 0x40 // ADC conversion command

#define CMD_PROM 0xA0 // Coefficient location

#define COEF0 17
#define COEF1 6
#define COEF2 16
#define COEF3 7
#define COEF4 10000
#define COEF5 1
#define COEF6 31
#define COEF7 61
#define COEF8 4
#define COEF9 2
#define COEF10 0
#define COEF11 20
#define COEF12 12
#define COEF13 0
#define COEF14 0
#define COEF15 0

#define PresADR 0x77
#define ADC_ADR 0x6B

#define SOF '['
#define EOF ']'

// Pins for ATTiny1634
#define SN_DE 13
#define SN_RE 14
#define REF_EN 4

uint16_t coefficient[8];// Coefficients;

int32_t _temperature_actual;
int32_t _pressure_actual;

float Pressure = 0; // MS5803 pressure
float Temp0 = 0; // Global tempurature from thermistor
float Temp1 = 0; // Global tempurature MS5803

// Register to be used to display the status of the sub modules
// Bits 0~1 used for status of ADC, bits 2~3 used for MS5803 status
uint8_t StatusReg = 0;

uint8_t ADR_Print = 13; //FIX make this less bad!
static const char GenADR[2] = {'9', '9'};
char ADR[2] = {'1', '3'}; //Used to read in and check ADR

char Format = 'f';
uint8_t Baud_Multiplier = 4;  // Baud = Baud_Multiplier * 1200

void setup() {
     DDRA = DDRA | 0x01; //Set pin A0 as OUTPUT
     PORTA = PORTA | 0x01; //DEBUG! Set A0 port, set A0 HIGH

    // Start communicating wtih ADC to thermistor and MS5803
    Wire.begin();
  	initADC();
  	initMS5803();

  	getValues(); // Update on power on

    // Start serial comunication over RS-485, start in "slow mode" to allow
    // for reset
  	Serial.begin(4800);

  	// For ATTiny 1634 -- aka Walrus
  	pinMode(SN_DE, OUTPUT);
  	pinMode(SN_RE, OUTPUT);
  	pinMode(REF_EN, OUTPUT);

    // Begin in minion mode by default, recieve on, transmit off
  	digitalWrite(SN_DE, LOW);
  	digitalWrite(SN_RE, LOW);
  	digitalWrite(REF_EN, HIGH);

    // If EEPROM is not initialized, like on initial firmware load,
    // then write addresses and BAUD_MULTIPLIER to it
    if(EEPROM.read(0x00) != 'F') {
        writeEEPROM();
    }
    // Otherwise, read address from EEPROM on startup
    else {
        ADR[0] = EEPROM.read(0x01);
        ADR[1] = EEPROM.read(0x02);
        Baud_Multiplier = EEPROM.read(0x03);
        ADR_Print = charToInt(ADR);
    }

    long LocalTime = millis();
    while(millis() - LocalTime < 1000) {
        // If 'ESCAPE' message is sent, reset to defaults!
        if(Serial.read() == '!') {
            reset();
            break;
        }
    }
    Serial.end(); //End previous serial instance

    // Restart Serial with general baud rate
    Serial.begin(Baud_Multiplier*1200);

    PORTA = PORTA & 0xFE; //DEBUG! Clear A0 port, set A0 LOW
}

void loop() {

    // Define variables
    char TempADR[2] = {0}; // Temporary address
    uint8_t RegID = 0; // Used to store int converted register value
    char Msg[10] = {0}; // 9 digits + null termanator?
    bool Neg = false; // Negative flag
    char Reg[2] = {0}; // Used to read in register ID

    while(Serial.read() != SOF); //Wait for SOF character //DEBUG!
    PORTA = PORTA | 0x01; //DEBUG! Set A0 port, set A0 HIGH

    while(Serial.available() < 4) { //FIX add timeout!  //DEBUG!
        // Must remain! I know it seems unessicary, but Scouts Honor, it's not!
        delay(1);
    };

    /////////////////////////////////////
    // Communication and data transfer //
    /////////////////////////////////////

    // Read temperary address that is provided
    // ADW: This looks to be some kind of digital handshake to make sure that
    // the sensor does not do anything unless it is supposed to
    TempADR[0] = Serial.read();
    TempADR[1] = Serial.read();

    // Proceed only if address matches unique, or general call
    if( (TempADR[0] == ADR[0] && TempADR[1] == ADR[1]) ||
        (TempADR[0] == GenADR[0] && TempADR[1] == GenADR[1]) )
        {
            // Set baud rate
            Reg[0] = Serial.read();
            Reg[1] = Serial.read();
            RegID = charToInt(Reg);
            if(RegID == 97) {
                //Wait for 1 byte FIX add timeout!
                while(Serial.available() < 1) {
                    delay(1);
                }
                // Must restart to take effect
                Baud_Multiplier = Serial.read() - 48;
                // Store baud value as integer
                if(Baud_Multiplier <= 96) EEPROM.write(0x03, Baud_Multiplier);
            }
            // Set address
            if(RegID == 99) {
                //Wait for 2 bytes FIX add timeout! DEBUG!
                while(Serial.available() < 2) {
                    delay(1);
                }
                ADR[0] = Serial.read();
                ADR[1] = Serial.read();
                // Convert into int for easier printing later FIX??
                ADR_Print = charToInt(ADR);
                if(ADR < 99) {
                // Write values to EEPROM for future use
                EEPROM.write(0x01, ADR[0]);
                EEPROM.write(0x02, ADR[1]);
            }
        }

        // Gets data of a given type based on the RegID provided
        float DataTemp = getData(RegID);
        // shift 3 decimal digits left to make it a whole number
        long Temp = long((DataTemp*float(1000.0)));
        if(Temp < 0) {
            // Convert to positive for now, will replace negative later
            // in conversion
            Temp = Temp*-1.0;
            // Set negative flag
            Neg = true;
        }

        // Get length of number to know when to stop.
        uint8_t Len = 1;
        // Check for 0 to prevent weird math/mem access issues
        if(Temp != 0) {
            Len = log10(Temp);
        }

        // Test if less than 1, but positive
        if(Temp < 1000 && Temp > 0) {
            // If so, add an additional place to generate a leading zero
            Len = Len + 1;
        }

        // Convert to ASCII
        for(int i = Len + 1; i > Len - 2; i--) {
            // Take lowest digit, convert to ASCII char
            Msg[i] = (Temp % 10) + 48;
            Temp /= 10; // Shift to the right one
        }
        Msg[Len - 2] = '.'; //Add decimal
        for(int p = Len - 3; p >= 0; p--) {
            // Take lowest digit, convert to ASCII char
            Msg[p] = (Temp % 10) + 48;
            Temp /= 10;
        }

        // If value is negative, shift values right and append '-' sign
        if(Neg) {
            for(int i = 9; i > 0; i--) {
                Msg[i] = Msg[i - 1];
            }
            Msg[0] = '-';
        }

        // Remove decimal and trailing zero for integer values
        if((Format == 'd' || Format == 'b') && Len > 2) {
            Len = Len - 2;
        }
        // Otherwise, add space for the values beyond the decimal
        if(Format == 'f') {
            Len = Len + 2;
        }

        // Transmit data
        digitalWrite(SN_RE, HIGH); // Disable recieve (to prevent loopback)
        digitalWrite(SN_DE, HIGH); // Enable transmit

        Serial.print(SOF);
        zeroPrepend(ADR_Print);
        zeroPrepend(RegID);
        for(int i = 0; i < Len; i++) {
            Serial.print(Msg[i]); // Print subset of Msg
        }
        Serial.print(Format);
        Serial.print(getCRC(Msg, Len));
        Serial.print(EOF);
        Serial.print("\n\r"); //Print formatter

        digitalWrite(SN_DE, LOW);  //Disable transmit
        digitalWrite(SN_RE, LOW);  //Enable recieve, return to normal operation
    }
    PORTA = PORTA & 0xFE; //DEBUG! Clear A0 port, set A0 LOW
}

///////////////
// FUNCTIONS //
///////////////

void zeroPrepend(uint8_t Val)
{
    if(Val < 10) {
        Serial.print('0');
    }
    Serial.print(Val);
}

uint8_t getValues()
{
    // Update global values from sensors
    getMeasurements();
    Pressure = _pressure_actual / (float(COEF4)/100.0);
  	Temp0 = getTempThermistor();
    Temp1 = _temperature_actual / 100.0;
    return StatusReg; // FIX to give status indication!
}

void initADC()
{
	Wire.beginTransmission(ADC_ADR);
	Wire.write(0x9C); // Set ADC to continuious conversion, 18 bits, 1V/V gain
	StatusReg = StatusReg | Wire.endTransmission(); // Lower 2 bits for ADC status
}

void initMS5803()
{
    uint8_t i;
    uint8_t Data[2] = {0};

    for(i = 0; i <= 7; i++){
        sendCommand(CMD_PROM + (i * 2));
        Wire.requestFrom(PresADR, 2);
        Data[0] = Wire.read();
        Data[1] = Wire.read();
        coefficient[i] = (Data[0] << 8)|Data[1];
    }
    //Bits 2~3 show the status of the MS5803
  	StatusReg = StatusReg | (sendCommand(CMD_RESET) << 2);
  	delay(3);
}

void getMeasurements()
// Gets resuts from ADC and stores them into internal variables
{
    //Retrieve ADC result
    int32_t temperature_raw = getADCconversionMS5803(0x10);
    int32_t pressure_raw = getADCconversionMS5803(0x00);

    //Create Variables for calculations
    int32_t temp_calc;
    int32_t pressure_calc;

    int32_t dT;

    //Now that we have a raw temperature, let's compute our actual.
    dT = temperature_raw - ((int32_t)coefficient[5] << 8);
    temp_calc = (((int64_t)dT * coefficient[6]) >> 23) + 2000;

    // TODO TESTING  _temperature_actual = temp_calc;

    //Now we have our first order Temperature, let's calculate the second order.
    int64_t T2, OFF2, SENS2, OFF, SENS; //working variables

    if (temp_calc < 2000)
    // If temp_calc is below 20.0C
        //LOW TEMP
    {
        T2 = COEF5* (((int64_t)dT * dT) >> COEF6);
        OFF2 = COEF7 * ((temp_calc - 2000) * (temp_calc - 2000)) / (pow(2,COEF8));
        SENS2 = COEF9 * ((temp_calc - 2000) * (temp_calc - 2000)) / (pow(2,COEF10));

       // if(temp_calc < -1500)  //Not needed for water???????
       // // If temp_calc is below -15.0C
       //     //VERY LOW TEMP
       // {
       //     OFF2 = OFF2 + COEF11 * ((temp_calc + 1500) * (temp_calc + 1500));
       //     SENS2 = SENS2 + COEF12 * ((temp_calc + 1500) * (temp_calc + 1500));
       // }
    }
    else
    // If temp_calc is above 20.0C
        //HIGH TEMP
    {
        T2 = COEF13 * ((uint64_t)dT * dT)/pow(2,COEF14);
        OFF2 = COEF15*((temp_calc - 2000) * (temp_calc - 2000)) / 16;
        SENS2 = 0;
    }

    // Now bring it all together to apply offsets
    OFF = ((int64_t)coefficient[2] << COEF0) + (((coefficient[4] * (int64_t)dT)) >> COEF1);    //05BA model!
    SENS = ((int64_t)coefficient[1] << COEF2) + (((coefficient[3] * (int64_t)dT)) >> COEF3); //05BA model!

    temp_calc = temp_calc - T2;
    OFF = OFF - OFF2;
    SENS = SENS - SENS2;

    // Now lets calculate the pressure
    pressure_calc = (((SENS * pressure_raw) / 2097152 ) - OFF) / 32768;

    _temperature_actual = temp_calc ;
    _pressure_actual = pressure_calc ; // 10;// pressure_calc;
}

uint32_t getADCconversionMS5803(uint8_t _measurement)
// Retrieve ADC measurement from the MS5803 device.
// Select measurement type and precision
// TODO:  Set up for asynchronous conversion? - ie, w/o waits
{
    uint8_t Data[3] = {0};
    sendCommand(CMD_ADC_CONV + _measurement + 0x08);
    // Wait for conversion to complete
    delay(10);

    StatusReg = StatusReg | (sendCommand(CMD_ADC_READ) << 2);

    Wire.requestFrom(PresADR, 3);

    while(Wire.available())  //REPLACE!
    {
        Data[0] = Wire.read();
        Data[1] = Wire.read();
        Data[2] = Wire.read();
    }
    return (long(Data[0]) << 16) + (long(Data[1]) << 8) + Data[0];
}

uint8_t sendCommand(uint8_t Command)
{
    Wire.beginTransmission(PresADR);
    Wire.write(Command);
    return Wire.endTransmission();
}

float getTempThermistor()
{
    uint8_t Data[3];
    float ThermB = 3380; //Basic B value for thermistor
    // Coefficients for enhanced accuracy
    // float ThermCoefs[4] = \
    //        {0.003354016, 0.0003074038, 1.019153E-05, 9.093712E-07};
    float VRef = 1.8; //Voltage referance used for thermistor
    float R0 = 10000; //Series resistor value with thermistor
    float ThermR = 10000; //Nominal resistace value for the thermistor

  	Wire.requestFrom(ADC_ADR, 4);
    delay(5); //DEBUG!
    // Get 3 bytes of potential data
  	if(Wire.available() == 4)
  	{
  		  Data[0] = Wire.read();
    		Data[1] = Wire.read();
    		Data[2] = Wire.read(); //DEBUG!
  	}
    StatusReg = StatusReg | Wire.endTransmission(); //DEBUG!

    // Voltage divider output
    float Val = ( ( (long(Data[0]) & 0x03 ) << 16 )
                  + (long(Data[1]) << 8)
                  + Data[2] )
                  * 1.5625e-5;
    // Voltage is measured across thermistor, not relative to ground
    Val = VRef - Val;

    float Rt = (VRef/Val)*R0 - R0;
    float T = 1/((1/ThermB)*log(Rt/ThermR) + 1/298.15);
    T = T - 273.15; // Convert to C
    return T; //DEBUG!
}

unsigned char getCRC(const unsigned char * data, const unsigned int size)
{
    // Cyclic redundancy check?
    unsigned char crc = 0;
    for ( unsigned int i = 0; i < size; ++i )
    {
        unsigned char inbyte = data[i];
        for ( unsigned char j = 0; j < 8; ++j )
        {
            unsigned char mix = (crc ^ inbyte) & 0x01;
            crc >>= 1;
            if ( mix ) crc ^= 0x8C;
            inbyte >>= 1;
        }
    }
    return crc;
}

uint8_t charToInt(char *data)
{
    return (data[0] - 48)*10 + (data[1] - 48);
}

float getData(uint8_t RegID)
{
    Format = 'd'; // Default to integer ("decimal", not point!)
    switch(RegID) {
        case 0:
            Format = 'f';
            // DecFigs = 3;
            return Pressure;
            break;

        case 1:
            Format = 'f';
            // DecFigs = 3;
            return Temp0;
            break;

        case 2:
            Format = 'f';
            // DecFigs = 3;
            return Temp1;
            break;

        case 5:
            //FIX! Print Self test
            Format = 'b';
            // DecFigs = 0;
            return getValues();
            break;

        case 80:  //read baud rate
            // Format = 'd';
            // DecFigs = 0;
            return MODEL;
            break;

        case 81:
            // Format = 'd';
            return GROUPID;
            break;

        case 82:
            // Format = 'd';
            return INDID;
            break;

        case 83:
            // Format = 'd';
            return FIRMWAREID;
            break;

        case 96:  //read baud rate
            // Format = 'd';
            // DecFigs = 0;
            return Baud_Multiplier*1200;
            break;

        case 97:  //Set baud rate
            // Format = 'd';
            return Baud_Multiplier*1200;
            break;

        case 98: //Read address
            Format = 'b';
            return ADR_Print;
            break;

        case 99:  //Set Address
            Format = 'b';
            return ADR_Print;
            break;
    }
}

void reset()
{
    ADR[0] = '1';
    ADR[1] = '3';
    Baud_Multiplier = 4;

    writeEEPROM();

    Serial.println("[r]");
}

void writeEEPROM()
{
    EEPROM.write(0x01, ADR[0]);
    EEPROM.write(0x02, ADR[1]);
    EEPROM.write(0x03, Baud_Multiplier);
    EEPROM.write(0x00, 'L'); //Write value to adr 0x00 to mark EEPROM as written
}

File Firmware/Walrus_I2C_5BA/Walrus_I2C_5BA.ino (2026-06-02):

//Dyson_Driver_ShortWave.ino
//v0.0.0

// #define SDA_PIN 3
// #define SDA_PORT portOutputRegister(1)
// #define SCL_PIN 2
// #define SCL_PORT portOutputRegister(1)


// #include "SoftI2CMaster.h"
// #include "WireS.h"
// #include <SoftWire.h>
// #include "SoftwareI2C.h"
#include <SlowSoftWire.h>
#include <Wire.h>
#include <EEPROM.h>
// #include <EEPROM.h> //DEBUG!
//Commands

#define CMD_RESET 0x1E // reset command
#define CMD_ADC_READ 0x00 // ADC read command
#define CMD_ADC_CONV 0x40 // ADC conversion command

#define CMD_PROM 0xA0 // Coefficient location

// //COEFS for MS5803_05BA
#define COEF0 18
#define COEF1 5
#define COEF2 17
#define COEF3 7
#define COEF4 10000
#define COEF5 3
#define COEF6 33
#define COEF7 3
#define COEF8 3
#define COEF9 7
#define COEF10 3
#define COEF11 0
#define COEF12 3
#define COEF13 0
#define COEF14 0
#define COEF15 0

//COEFS for MS5803_02BA
// #define COEF0 17
// #define COEF1 6
// #define COEF2 16
// #define COEF3 7
// #define COEF4 10000
// #define COEF5 1
// #define COEF6 31
// #define COEF7 61
// #define COEF8 4
// #define COEF9 2
// #define COEF10 0
// #define COEF11 20
// #define COEF12 12
// #define COEF13 0
// #define COEF14 0
// #define COEF15 0

//COEFS for MS5803_14BA
// #define COEF0 16
// #define COEF1 7
// #define COEF2 15
// #define COEF3 8
// #define COEF4 1000
// #define COEF5 3
// #define COEF6 33
// #define COEF7 3
// #define COEF8 1
// #define COEF9 5
// #define COEF10 3
// #define COEF11 7
// #define COEF12 4
// #define COEF13 7
// #define COEF14 37
// #define COEF15 1

#define CTRL 0x00  //Define location of onboard control/confiuration register

const uint8_t PresADR = 0x77;
// const uint8_t TempADR = 0x18; 
const uint8_t TempADR = 0x18; 



// #define CONF_CMD 0x00
// #define ALS_CMD 0x04
// #define WHITE_CMD 0x05

// #define UVA_CMD 0x07
// #define UVB_CMD 0x09
// #define COMP1_CMD 0x0A
// #define COMP2_CMD 0x0B

// #define ADC_CONF 0x01
// #define ADC_CONV 0x00
// #define ADC0 0x4200
// #define ADC1 0x5200
// #define ADC2 0x6200
// #define ADC3 0x7200

// #define VIS_ADR 0x48
// #define UV_ADR 0x10
// #define ADC_ADR 0x49

#define READ 0x01
#define WRITE 0x00

// #define BUF_LENGTH 64 //Length of I2C Buffer, verify with documentation 

// #define LOW_LIM_VIS 10000  //Lower limit to the auto ranging of the VEML6030
// #define HIGH_LIM_VIS 55000 //Upper limit to the auto ranging of the VEML6030

// #define ADR_SEL_PIN 7 //Digital pin 7 is used to test which device address should be used

// #define MODEL 0x5702
// #define GROUPID 0x1701 //Default for lab
// #define INDID 0x0000 //Dummy
// #define FIRMWAREID 0x0001 //Base firmware ID

const unsigned int MODEL = 0x5702; //DEBUG!
const unsigned int GROUPID = 0x1701; //Default for lab
const unsigned int INDID = 0x0000; //Dummy
const unsigned int FIRMWAREID = 0x0001; //Base firmware ID

uint16_t coefficient[8];// Coefficients;

int32_t _temperature_actual;
int32_t _pressure_actual;

float Pressure = 0; // MS5803 pressure
float Temp0 = 0; // Global tempurature from thermistor
float Temp1 = 0; // Global tempurature MS5803
// #define ADR_ALT 0x41 //Alternative device address

uint8_t StatusReg = 0; //Register to be used to display the status of the sub modules , Bits 0~1 used for status of ADC, bits 2~3 used for MS5803 status

// //Global values for gain and int time of visable light sensor
// uint8_t Gain = 0;
// unsigned int IntTime = 0;
// uint8_t GainValsVis[4] = {0b10, 0b11, 0b00, 0b01}; //Gain values for visible sensor
// uint8_t GainsVis[4] = {1, 2, 8, 16}; //Gain multipliers for visable sensor 
// uint8_t IntTimeValsVis[6] = {0b1100, 0b1000, 0b0000, 0b0001, 0b0010, 0b0011}; //Integration time values for visible sensor

// //Compensation constants
// float a = 1.92;
// float b = 0.55;
// float c = 2.46;
// float d = 0.63;

const uint8_t ModeSelPin = 2; //Pin to select between I2C and RS-485

volatile uint8_t ADR = 0x57; // Schema 1: 'W' (ASCII mnemonic); former 0x4D clashed with Margay

uint8_t Config = 0; //Global config value

uint8_t Reg[64] = {0}; //Initialize registers; 0x00–0x1F = Page 0 (identity), 0x20–0x3F = Page 1 (sensor data)
bool StartSample = true; //Flag used to start a new converstion, make a conversion on startup
// const unsigned int UpdateRate = 5; //Rate of update
const unsigned int UpdateRate[] = {5, 10, 60, 300}; //FIX with better numbers! 

// SoftWire si(PIN_PA2, PIN_PA3);  //Initialize software I2C
// SoftwareI2C si;
// SoftWire si = SoftWire();
// SoftwareWire si(PIN_PA3,PIN_PA2);

SlowSoftWire si = SlowSoftWire(PIN_PA2, PIN_PA3);
volatile bool StopFlag = false; //Used to indicate a stop condition 
volatile uint8_t RegID = 0; //Used to denote which register will be read from
volatile bool RepeatedStart = false; //Used to show if the start was repeated or not

// #define I2C_MAXWAIT 3

void setup() {

  pinMode(ModeSelPin, OUTPUT);
  digitalWrite(ModeSelPin, LOW); //Set device to I2C mode 
  // Serial.begin(115200); //DEBUG!
  // Serial.println("begin"); //DEBUG!
  Reg[CTRL] = 0x00; //Set Config to POR value
  //SETUP HARDWARE!
  //SET CONTROL FOR I2C vs RS-485!!!!!!!!!!!!
  // pinMode(ADR_SEL_PIN, INPUT_PULLUP);
  // pinMode(10, OUTPUT); //DEBUG!
  // pinMode(9, OUTPUT); //DEBUG!
  // digitalWrite(10, HIGH); //DEBUG!
  // digitalWrite(9, LOW); //DEBUG!
  // if(!digitalRead(ADR_SEL_PIN)) ADR = ADR_Alt; //If solder jumper is bridged, use alternate address //DEBUG!

  Wire.begin(ADR);  //Begin slave I2C
	Wire.onRequest(requestEvent);     // register event
  Wire.onReceive(receiveEvent);
    si.begin(); //Must start AFTER hardware I2C!
  
  // EEPROM.write(0, ADR);

  //INIT DEVICES!
  // Start communicating wtih ADC to thermistor and MS5803
   // Wire.begin();
    // initADC();
    // si.i2c_init(); //Begin I2C master

    // si.begin();
    initTemp(); //DEBUG! REPLACE!
    initMS5803(); //DEBUG! REPLACE!
    // delay(500); //DEBUG!
    getValues(); // Update on power on //DEBUG!

  //Setup I2C slave
  // Wire.onAddrReceive(addressEvent); // register event


  
  // Wire.onStop(stopEvent);



  // AutoRange_Vis(); //Auto range for given light conditions
  // digitalWrite(9, HIGH); //DEBUG!
  // digitalWrite(10, LOW); //DEBUG!
}
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

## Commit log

2018-10-27 Larger board, mid-route * QFN packages * ISP header * solder holes for the cable * Hand-routed * Most pogo pads removed
    [TPDH-Walrus.brd, TPDH-Walrus.sch]
2018-10-27 PTH ISP, more routing
    [TPDH-Walrus.brd, TPDH-Walrus.sch]
2018-10-31 multiple schematic and layout updates * status indicator * LDO reset * move thermistor by power supply and voltage reference * rip up traces and reorganize
    [TPDH-Walrus.brd, TPDH-Walrus.sch]
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2018-10-31 Level shifter on schematic
    [TPDH-Walrus.brd, TPDH-Walrus.sch]
2018-10-31 Connected level shifter, added passives
    Added schematic connections for level shifter, also added decoupling capacitors and relabeled IC values
    [TPDH-Walrus.brd, TPDH-Walrus.sch]
2018-11-01 all components approx placed
    [TPDH-Walrus.brd]
2018-11-02 Update +3V3 symbol and re-route
    [TPDH-Walrus.brd, TPDH-Walrus.sch]
2018-11-02 1 via, lots of work
    [TPDH-Walrus.brd]
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2018-11-03 Cable solder ring silk
    [TPDH-Walrus.brd]
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2018-11-05 Minor fixes for DRC
    Changed power path very slightly, also changed to 0.2mm traces for TSX0102 to avoid clearance issues
    [TPDH-Walrus.brd]
2018-11-05 Major revision Add 10 uF cap Reroute to keep decoupling caps near ICs Change schematic to reflect the above reorganization Reroute to move thermistor to upper right
    [TPDH-Walrus.brd, TPDH-Walrus.sch]
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2018-11-06 add SDO for I2C
    [TPDH-Walrus.brd, TPDH-Walrus.sch]
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2018-11-06 Fixed thermistor divider, removed SDO
    Changed thermistor voltage to VRef rather than 3v3, and removed connection to SDO pin.
    [TPDH-Walrus.brd, TPDH-Walrus.sch]
2018-11-07 Therm: reconnect and rearrange
    [TPDH-Walrus.brd]
2018-11-07 power pad update; uniform board outline
    [TPDH-Walrus.brd, TPDH-Walrus.sch]
2018-11-07 Update clearance, wire access; reroute
    [TPDH-Walrus.brd]
2018-11-07 top and bottom cable silk
    [TPDH-Walrus.brd]
2018-11-07 I2C silk - DEFAULT: 0x77, ALT: 0x76
    [TPDH-Walrus.brd]
2018-11-07 Improved power layout, minor edits
    Improved the overall layout of the power (3v3 and GND) as well as a few other minor edits. Changed orientation of I2C pins to match previous designs, also made pad on SN65HVD33 floating
    [TPDH-Walrus.brd, TPDH-Walrus.sch]
2018-11-08 Clean up routing, clear DRC stubs
    [TPDH-Walrus.brd]
2018-11-08 Approve ERC: no value for pad, holes
    [TPDH-Walrus.sch]
2018-12-17 Silk placement and OSH logo
    [TPDH-Walrus.brd, TPDH-Walrus.sch]
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2018-12-24 Updated silk for production
    [TPDH-Walrus.brd]
2019-01-04 Minor silk screen updates, generated gerbers
    Minor silk screen updates for v0.0.0 before submitting to fab, generated gerbers and sent to fab
    [TPDH-Walrus.brd]
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2019-01-19 Added first Gen1 housing
    Added solidworks and STL file for first generation of housing
    [Walrus_Box_Body.SLDPRT, Walrus_Box_Body.STL, Walrus_Box_Lid.SLDPRT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]
2019-02-02 Updated firmware to support `Wire.h`
    Changed firmware to use most well supported (and much faster!) Wire hardware library, now that we no longer need to use a software implementation due to memory constriction
2019-07-08 Updates to BOM info and silkscreen
    [TPDH-Walrus.sch, TPDH-Walrus_BOM.csv]
2019-07-08 Initial hardmount variant
    Start of hard mount variant design, several design update choices required
    [TPDH-Walrus_HardMount.brd, TPDH-Walrus_HardMount.sch]
2019-07-10 Updated silkscreen on Walrus v0.0
    [TPDH-Walrus.brd]
2019-07-10 Initial layout for Hard mount (v0.1) variant, cleanup required
    [TPDH-Walrus_HardMount.brd, TPDH-Walrus_HardMount.sch]
2019-07-11 Continued layout, final cleanup required
    Cleanup and pours required
    [TPDH-Walrus_HardMount.brd, TPDH-Walrus_HardMount.sch]
2019-07-15 Minor layout updates, sent to fab
    Cleaned up layout, sent to fab
    [TPDH-Walrus_HardMount.brd, TPDH-Walrus_HardMount.sch]
2019-08-03 Added BOM for hard mount, minor part number cleanup
    [TPDH-Walrus_HardMount.brd, TPDH-Walrus_HardMount.sch, TPDH-Walrus_HardMount_BOM.csv]
2019-08-13 Update to v0.1 hardware, review required
    Initial update complete, requires review and verification of various fixes
    [TPDH-Walrus_HardMount.brd, TPDH-Walrus_HardMount.sch]
2019-08-13 Board cleanup, final DFM for v0.2, added gerbers
    [TPDH-Walrus_HardMount.brd]
2019-09-25 Added hole dimension callouts to Walrus v1
    Added callouts to board file and added separate picture for easy reference
    [TPDH-Walrus.brd]
2019-09-25 Added preliminary design for v2 alternative mounting
    Added a v2 design with mounting pattern which is compatible with the v1 Walrus and no removable connector
    [TPDH-Walrus_v2_NoConn.brd, TPDH-Walrus_v2_NoConn.sch]
2019-09-26 Minor updates and cleanup, sent v2 NoConn to fab
    Minor silkscreen and trace cleanup, sent v2 of through hole variant out to fab
    [TPDH-Walrus_v2_NoConn.brd, TPDH-Walrus_v2_NoConn.sch]
2020-02-20 Generated updated BoM
    Updated BoM to fix R1 part value
    [TPDH-Walrus_HardMount_BOM.csv]
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2020-04-25 Original PTH and enclosure to its folder
    [TPDH-Walrus.brd, TPDH-Walrus.sch, TPDH-Walrus_BOM.csv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]
2020-04-25 4-pin version in Hardware_LargePTH
    [TPDH-Walrus_4pinPTH.brd, TPDH-Walrus_4pinPTH.sch]
2020-04-25 Proper attribution to Schulz
    [TPDH-Walrus_4pinPTH.brd, TPDH-Walrus_HardMount.brd]
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2020-04-30 Move housings into 3Dprint folder
    [Walrus_Box_Body.SLDPRT, Walrus_Box_Body.STL, Walrus_Box_Lid.SLDPRT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]
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2020-05-07 Updated part numbers and BoM for HardMount variant
    Updated part numbers in BoM to specifically indicate DNP where appropriate and to change MS5803 PN to 2BA model instead of 5BA model
    [TPDH-Walrus_HardMount.brd, TPDH-Walrus_HardMount.sch, TPDH-Walrus_HardMount_BOM.csv]
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2020-06-19 Rev A (captured screw, captured pipe screen)
    Rev A Walrus potting mold and sensor housing
    [0.25inch Brass Pipe screen.SLDPRT, 929665-09-03^Walrus_HardMount_Assembly.SLDASM, Epoxy_housing.SLDPRT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]
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2020-08-06 Fixed negative values for MCP9808
    Fixed math error which caused incorrect values for MCP9808 (`TempDH`) temp readout
    [Walrus_I2C_5BA.ino]
2020-08-06 Ohhhhhhh.... VCC and GND power colors flipped!
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2020-08-08 "Bootloader" for fuses: Oscillator + brown-out detection
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2021-02-13 Missing files that constitute the assembly
    [Housing_Assemblies.SLDASM]
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2021-02-13 Newest housing with epoxy-fill tray and external enclosure designed by @superchap123
    [WalrusEnclosure.step, WalrusHardMount_Housing_EpoxyTray.stl, WalrusHardMount_Housing_ExteriorCylinder.stl]
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2026-06-02 Add register map section: current and proposed Schema 1 layouts
    Documents the existing 26-byte prototype register map (identity mixed
    into sensor data, status bit 7, 1/10000°C temperature) alongside the
    proposed NW-Device-Specification Schema 1 layout (Page 0 identity/EEPROM,
    Page 1 sensor data/SRAM grouped by chip). Includes three open items that
    must be resolved before firmware update: status bit position, temperature
    precision, and pressure unit consistency with Haar.
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2026-06-02 README: fix MCU — ATtiny1634, not ATMega
    The Walrus uses an ATtiny1634; the earlier description of an "ATMega
    microcontroller" was incorrect. Programming instructions in the same
    file already correctly said ATtiny1634.
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2026-06-02 Firmware: flip ready flag from bit 7 to bit 0 (Schema 1)
    Schema 1 standardises the ready flag at bit 0 of the status byte.
    The firmware was using bit 7 (0x80). Move to bit 0 (0x01) for both
    the clear-before-update and set-after-update operations. Also remove
    the redundant double-assignment (Reg[CTRL] = Reg[CTRL] &/|=).
    [Walrus_I2C_5BA.ino]
2026-06-02 Revert "Firmware: flip ready flag from bit 7 to bit 0 (Schema 1)"
    This reverts commit 7fc8bd6b5a46fda533f78a189a5199bab5478194.
    [Walrus_I2C_5BA.ino]
2026-06-02 Page 1 status byte: add pan-fault (bit 7), label 0x27 as extended fault byte; resolve pressure-unit open item
    Reflects the NW-Device-Specification Schema 1 standard: bit 7 is the
    pan-fault summary; 0x27 is the reserved extended fault byte.
    Removes the pressure-unit open item — µBar is intentional for the Walrus
    (matches the MS5803 library's native output); the difference from the
    Haar's 0.01 hPa is documented in NW-Device-Specification as deliberate.
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

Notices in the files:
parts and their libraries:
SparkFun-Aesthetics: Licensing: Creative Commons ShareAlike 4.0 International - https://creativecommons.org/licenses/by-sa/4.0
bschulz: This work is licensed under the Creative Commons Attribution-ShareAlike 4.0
